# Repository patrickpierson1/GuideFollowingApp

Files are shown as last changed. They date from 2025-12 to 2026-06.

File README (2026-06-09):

AIChair: Guide Following Documentation
By Joseph Loreen, Marlen Vining and Patrick Pierson

1.0 Project Overview
AIChair Guide Following is a wheelchair person following system designed to help wheelchair users navigate by following a person. The system is designed to provide an accessible and user-friendly interface to a YOLO backend for the autonomous tracking and following of a human guide. It enables a user to select a person for the system to follow. 

The system will then drive the chair to maintain a set distance from the guide. The system consists of an IOS app as a frontend and a Raspberry Pi as a backend. The app includes a view from the camera, a toggle for the backend tracking, the ability to select one of the tracked people to follow, and a settings menu. The backend uses a YOLO object detection model to draw boxes around any people in the images provided by the frontend. It uses the position of these boxes to drive the chair through the injection of RNET messages to face and follow the guide.

This documentation covers the setup of both the frontend application and the backend. It also provides an explanation of the key functions in each part of the system. This documentation ends with an overview of how the system functions and some limitations we have encountered. 

2.0 Backend Application
2.1 Overview
The backend application is designed to run on a Raspberry Pi 5 and serves as the main processing and control layer for the guide-following wheelchair system. It communicates wirelessly with the frontend application, which streams image frames from the phone camera to the backend in real time. The backend processes each incoming image, performs person detection, tracks detected individuals across frames, and generates control commands that are sent to the wheelchair through the RNET communication system.
Human detection is performed using YOLO, which identifies people within each received camera frame and returns bounding box information for each valid detection. Detections below the configured confidence threshold are discarded to reduce false positives and improve tracking reliability. Once detections are generated, the tracking system assigns and maintains consistent IDs for each detected person. This allows the backend to distinguish between multiple people in the frame and continue identifying the same individual as they move.
Person tracking is handled using an intersection-over-union based tracking approach. For each new frame, the tracker compares the bounding boxes from the current YOLO detections against the bounding boxes from the previous frame. If two bounding boxes overlap enough, they are treated as the same person and the previous ID is preserved. This allows detections to be mapped to stable person IDs over time.
The backend supports different operating states. In tracking mode, the system detects and tracks all visible people, allowing the frontend to select a specific person ID. Once a target person is selected, the backend transitions into following mode. In following mode, the backend monitors the selected person’s bounding box, calculates the normalized center position of that person in the frame, and determines the direction the wheelchair should move in order to follow them. These direction commands are written to a shared thread-safe control interface.
The control system reads these shared joystick values and converts them into RNET-compatible CAN messages. These messages emulate joystick commands and are injected onto the wheelchair CAN bus, allowing the backend to command movement through the chair’s existing motor controller interface. This separates the image-processing pipeline from the low-level chair-control pipeline while still allowing both systems to communicate safely through shared mutex-protected variables.
2.2 System Requirements
Hardware Requirements
The backend is intended to run on the following hardware:
Raspberry Pi 5
Raspberry Pi AI HAT rated for 14 TOPS
PiCAN HAT with DC/DC power support
RNET-compatible powered wheelchair system
CAN connection from the PiCAN HAT to the wheelchair RNET bus
The PiCAN HAT is used to interface with the wheelchair’s CAN network. The AI HAT is used to improve the performance of the image-processing pipeline, particularly YOLO-based human detection. The Raspberry Pi 5 acts as the central embedded computer that receives image data, runs backend logic, and sends control commands to the chair.
Software Requirements
The Raspberry Pi should be configured with a functional 64-bit Raspberry Pi OS image. Python must be installed, and a fresh virtual environment is recommended to isolate the backend dependencies from the system Python installation.
The backend requires Python packages for computer vision, machine learning inference, CAN communication, API hosting, and image handling. These packages are installed automatically using the provided setup.sh script.
2.3 Setup Instructions
Clone the Repository
Clone the project repository locally on the Raspberry Pi:
git clone https://github.com/patrickpierson1/GuideFollowingApp.git
Move into the backend directory:
cd GuideFollowingApp/backend
Connect the PiCAN HAT to the Wheelchair
Ensure that the PiCAN HAT is properly installed on the Raspberry Pi and connected to the wheelchair CAN bus. The chair-side wiring should be connected as follows:
12V  : Red wire
GND  : Black wire
CAN High : White wire
CAN Low  : Blue wire
Before powering the system, confirm that the wiring is secure and that CAN High and CAN Low are not reversed.
Run the Setup Script
The backend includes a setup.sh script to automate software setup. Instead of installing each package manually, run the setup script from inside the backend directory:
./setup.sh
If the script does not have execute permission, enable it first:
chmod +x setup.sh
./setup.sh
The setup script installs the required backend dependencies and prepares the Python environment. This includes packages for CAN communication, numerical processing, machine learning inference, API hosting, image processing, and YOLO object detection.
The setup script installs and configures dependencies such as:
python-can      CAN communication support from Python
can-utils       Linux CAN utilities for configuring and testing CAN interfaces
numpy           Numerical processing for detection and tracking data
torch           PyTorch machine learning framework
torchvision     Computer vision support for PyTorch
torchaudio      Audio package bundled with the PyTorch install set
fastapi         Backend API framework used to communicate with the frontend
uvicorn         ASGI server used to run the backend application
ultralytics     YOLO model support
pillow          Image loading and processing
python-multipart Support for receiving image uploads from the frontend
The script should be run before starting the backend for the first time. A fresh Python virtual environment is still recommended so that all packages remain isolated from the system Python installation.
Enable CAN Support
The Raspberry Pi must be configured to recognize the PiCAN HAT and enable the CAN interface. Add the following lines to the bottom of: /boot/firmware/config.txt
dtparam=spi=on
dtoverlay=mcp2515-can0,oscillator=16000000,interrupt=25
dtoverlay=spi-bcm2835-overlay
These configuration lines enable SPI communication and load the MCP2515 CAN controller overlay used by the PiCAN HAT.
After editing the configuration file, reboot the Raspberry Pi:
sudo reboot
Open the CAN Port and Set the Bit Rate
Once the Raspberry Pi has rebooted, initialize the CAN interface with a bit rate of 125000:
sudo /sbin/ip link set can0 up type can bitrate 125000
This opens the can0 interface and configures it to communicate at the correct RNET CAN bus speed.
To verify that the CAN interface is active, run:
ip link show can0
The interface should appear as active before running the backend.
Run the Backend
Start the backend server using Uvicorn:
uvicorn backend:app --reload --host 0.0.0.0 --port 8000 --no-access-log
Running with --host 0.0.0.0 allows the frontend device to connect to the Raspberry Pi over the local wireless network. The backend listens on port 8000.
After the backend starts, copy the Raspberry Pi’s IP address into the frontend application so the phone can send image frames to the backend.
2.4 File Structure
/backend/backend.py
backend.py is the main entry point for the backend application. It initializes the image-processing and control systems required for operation. On startup, it loads the YOLO models, initializes the person tracker, and starts a separate process for RNET communication with the wheelchair.
When the frontend sends an image frame to the backend, the frontend calls the backend detection endpoint. This causes backend.py to pass the image to the detection pipeline, where YOLO is used to identify people in the frame. The resulting detections are then passed to the tracking module, which updates person IDs and returns tracked detection data.
The backend then checks the current operating state. In tracking mode, it returns the detected people and their IDs so the frontend can display and select a target. In following mode, it uses the selected target ID to determine the person’s position in the frame and updates the shared joystick command values in Shared.py. These shared values are later read by the RNET injection system and converted into motor commands.
When the backend shuts down, active threads and processes are cleaned up automatically to prevent communication or control threads from continuing after the application has stopped.
Image Processing
/backend/ImageProcessing/detect.py
This module is responsible for running YOLO-based human detection. It receives image data from the backend, performs inference using the loaded YOLO model, and returns bounding box results for detected people.
The module filters detections based on a minimum confidence threshold. Any detection below this threshold is ignored. This reduces the chance of false detections being passed into the tracker and improves the reliability of the follow behavior.
The output of this module includes normalized detection data that can be used by the tracking system and frontend display logic.
/backend/ImageProcessing/track.py
This module manages person tracking across consecutive frames. Since YOLO detects people independently in each image, the raw detection results do not automatically preserve identity between frames. The tracking module solves this by assigning each detected person a persistent ID.
The tracker compares bounding boxes from the current frame to bounding boxes from the previous frame using intersection over union. If a current detection overlaps sufficiently with a previous detection, it is treated as the same person and keeps the same ID. If no suitable match is found, a new ID is assigned.
This allows the system to maintain consistent person identities even as people move through the camera frame. The module returns normalized detections with their associated person IDs.
/backend/ImageProcessing/guide.py
This module calculates the position of the selected tracked person relative to the camera frame. It uses the bounding box of the selected target and computes the center point of that box.
The returned center position is normalized so it can be interpreted as a directional guide value rather than a raw pixel coordinate. This normalized target location is used by the following logic to determine whether the wheelchair should move left, right, forward, or remain centered behind the selected person.
The guide module acts as the connection between visual tracking and motion control. It converts tracked image-space position into a simplified control reference that can be used by the chair-control system.
Controls
/backend/Controls/can2RNET.py
This module provides RNET communication support over CAN. It is a publicly available module used to help send, receive, inject, and dissect CAN frames on the wheelchair’s RNET communication bus.
Within this backend, can2RNET.py supports the lower-level CAN frame operations needed by the injection system. It allows the backend to construct and transmit messages that emulate joystick behavior on the RNET bus.
/backend/Controls/Connect.py
This module initializes the CAN connection to the wheelchair. It opens the CAN socket, prepares the system for RNET communication, and starts the required communication threads.
When enabled, this module can also start a keyboard input thread for manual joystick control. This is useful for testing CAN communication and motor response without running the image-detection pipeline.
During operation, Connect.py prints joystick commands being sent to the motor. This provides feedback for debugging and makes it easier to verify that the shared joystick values are being converted into outgoing control commands.
When the backend or control process is closed, this module handles thread cleanup so that injection and input-listening threads terminate properly.
/backend/Controls/Inject.py
This module is responsible for constructing and injecting joystick-emulation CAN frames. It first determines the correct joystick CAN ID used by the chair’s RNET system. Once the joystick ID is known, it builds CAN frames that represent joystick movement commands.
The joystick values are read from Shared.py. These values represent the desired x and y joystick position, which may come from the image-following system or from manual keyboard control. Inject.py converts these shared values into RNET-compatible CAN messages and injects them onto the CAN bus.
This module is the final step between the backend’s control decision and the wheelchair motor controller. It translates high-level movement commands into low-level CAN traffic.
/backend/Controls/KeyboardCtrl.py
This optional module listens for keyboard input from the terminal and updates joystick commands based on arrow-key input. It is mainly intended for testing and debugging the RNET control path without using the camera or YOLO detection pipeline.
When an arrow key is pressed, the module updates the shared joystick x and y values in Shared.py. These values are then read by the injection system and sent to the wheelchair as joystick commands.
Note: KeyboardCtrl.py should not be run at the same time as image detection or following mode. Both systems update the same shared joystick command values, so running them together may cause conflicting control commands.
/backend/Controls/Shared.py
This module provides a shared mutex-protected interface for joystick control values. It stores the joystick x and y variables and provides functions for safely updating or resetting them from multiple threads.
Because the backend uses separate processes and threads for detection, tracking, keyboard input, and CAN injection, shared state must be protected to prevent inconsistent or conflicting values. Shared.py acts as the common communication point between these systems.
The image-following pipeline writes updated movement commands to Shared.py, while the CAN injection system reads from it when building joystick frames. This allows the system to separate perception logic from low-level chair control while still maintaining safe communication between threads.

3.0 Swift App Documentation
3.1 Overview
The AIChair Guide Following app captures live video from the iPhones camera and sends the frames to the Python backend for processing. The backend performs person detection and tracking then returns bounding box coordinates which the app then displays on screen. Users can tap these boxes to select which person the wheelchair should lock onto and follow.

The app also uses the iPhones LiDAR camera to estimate the distance of detected individuals. For each detected person the app samples multiple points inside the bounding box and uses the minimum depth value to estimate the distance. This distance is then displayed on the bounding box associated with the detected person and is used to help maintain a safe following distance from the guide.

The app is written in Swift using SwiftUI. When tracking is enabled frames from the camera are sent to the backend using HTTP POST requests. Currently the app communicates with the backend through a hotspot hosted by the Raspberry pi which allows the app and backend to communicate without relying on an external network.

3.2 System Requirements
Hardware:
iPhone that supports iOS 15 or later and includes a LiDAR sensor for depth estimation (We are testing on an iPhone 13 Pro)
Raspberry Pi running the backend and hosting a hotspot connection
Development:
macOS with Xcode
Apple ID for deploying the app through Xcode

3.3 Setup Instructions
First Time Setup instructions on Xcode
Clone the repository from GitHub
Open the project in Xcode
Plug your iPhone into your Mac using a USB cable. You'll be asked on your phone if you trust this computer and select trust.
In Xcode select Window -> Devices and Simulators and make sure your iPhone appears under Connected devices.
In the left sidebar of Xcode click the project name in this case GuideFollowing. Then go to Signing & Capabilities.
Under team select your Apple ID. If it's not listed add your Apple account. Make sure Automatically manage signing is enabled.
Select your iPhone as the run destination at the top of Xcode
Click the run button or press Cmd + R to build and install the app onto your phone.
Since it's your first time running the app your iPhone will display Untrusted Developer. On your phone go to Settings -> General -> VPN & Device Management - > Developer app -> Trust
Launch the app and make sure to allow Camera Access.
After First Setup: The app will be installed on your phone and can be launched directly from it. If you make any code changes, rebuild and run from Xcode. Once your phone has been paired with your mac you can build wirelessly. Just make sure that both your mac and iPhone are on the same WiFi.

3.4 File Structure
/swift-app/GuideFollowing/CameraView.swift
Main interface for the app
Displays the live camera feed and overlays bounding boxes using the detection results from the backend
Handles user interaction for selecting a guide, starting and stopping tracking, pressing the move and stop button, and opening the settings menu
boxRect() converts the backend coordinates into on screen box positions and dimensions.
Displays status when someone is selected like “Following ID: _” or “Lost Track of ID: _”
Displays the ID and distance estimate associated with each detected person
/swift-app/GuideFollowing/CameraManager.swift
Handles all camera functionality
Sets up the camera session and captures frames using AVCaptureSession
Calls captureOutput() when a frame is ready
Passes frames through the onFrameCaptured closure
Captures depth data from the iPhone’s LiDAR camera and passes it through the onDepthCaptured closure
/swift-app/GuideFollowing/NetworkManager.swift
Handles communication between the app and the backend server
Converts frames into JPEG images and sends them to the /detect endpoint using HTTP POST
buildRequest() builds the HTTP POST request with the JPEG Image, selected guide ID, movement status, stopping distance, and maximum speed
Decodes the returned JSON data into DetectedPerson objects and updates the UI
Calculates distance estimates using the iPhone depth map by sampling 5 points inside each detected person’s bounding box and taking the minimum depth value
There are also functions for starting and stopping tracking, and resetting the ID tracker
/swift-app/GuideFollowing/SettingsView.swift
Allows the user to edit the backend IP address
Displays backend connection status
Allows the user to adjust stopping distance using a slider
Allows the user to adjust maximum following speed using a slider
Includes a Reset Tracker button to clear all tracked IDs and restart tracking
/swift-app/GuideFollowing/GuideFollowingApp.swift
Entry point for the app
Launches CameraView as the main screen

3.5 How it works
When the app is launched CameraManager initializes the iPhone camera and begins capturing video frames and depth data from the LiDAR camera. These frames are displayed in CameraView which shows the live feed to the user. When tracking is enabled each captured frame is sent to the backend server through NetworkManager along with information such as the selected guide ID, movement status, stopping distance, and maximum speed. The backend performs person detection and tracking using the YOLO model and returns a list of detected people along with their bounding box coordinates and tracking IDs.

NetworkManager converts this response into DetectedPerson objects and calculates a distance estimate for each detected person using the iPhones depth map. This is done by sampling five points inside each detected person’s bounding box and using the minimum depth value as the estimated distance. The calculated distance is then assigned to the detected person.

Once the detected people array is updated SwiftUI automatically redraws the interface and updates the bounding boxes, IDs, and distance values displayed on screen.

Users can then tap on the bounding box to select which person the wheelchair should follow. The selected ID is highlighted in the interface and is included in the future requests sent to the backend so the same guide can continue to be tracked across frames. Once a guide has been selected the user can press the Move button to begin following them while maintaining the chosen stopping distance.

3.6 Limitations
Tracking ID problems: The tracking IDs assigned to people can change if a person leaves the camera frame for a few seconds or if people overlap.
Low frame rate, roughly ~2 fps makes following a guide around harsh corners difficult

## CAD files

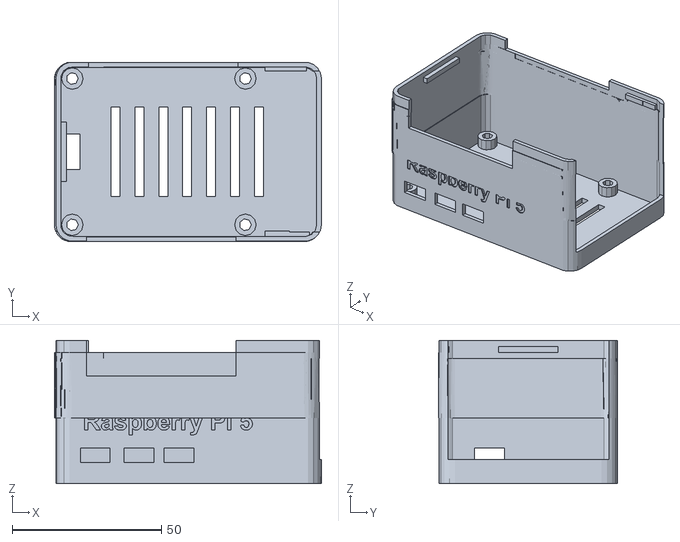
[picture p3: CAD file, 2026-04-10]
case-models/case.stl
89.5 x 60.1 x 48.0

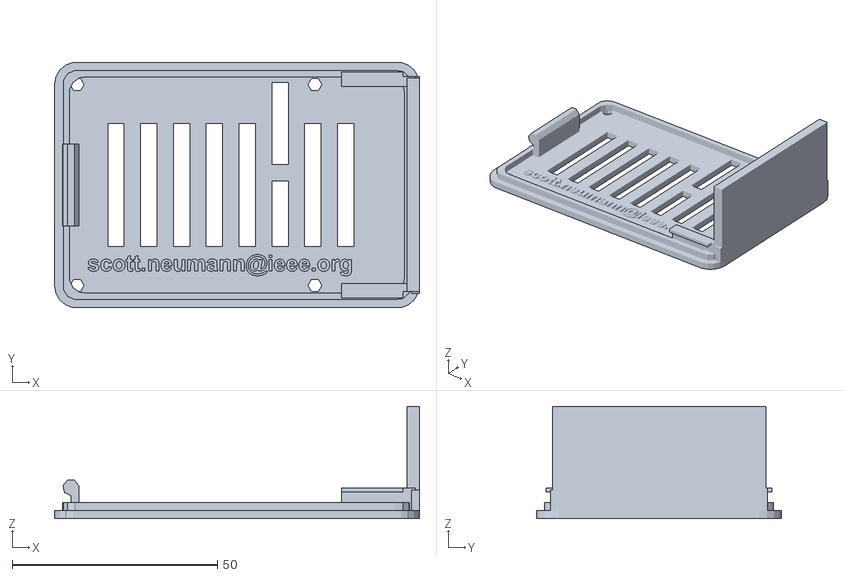
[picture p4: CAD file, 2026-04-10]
case-models/lid.stl
89.0 x 59.8 x 27.4

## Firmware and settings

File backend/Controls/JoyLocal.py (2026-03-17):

#!/python3
# joystick based on: https://www.kernel.org/doc/Documentation/input/joystick-api.txt

#Requires: socketCan, can0 interface

# This file is part of can2RNET.
#
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
import socket, sys, os, array, threading
from time import *
from fcntl import ioctl
from can2RNET import *


debug = True


#JoyLocal.py - Translate USB joystick x/y axis to Rnet and inject onto canbus
class X360:

    axis_map = []
    button_map = []
    xthreshold = 8 * 0x10000 / 128
    ythreshold = 8 * 0x10000 / 128

    joystick_x = 0
    joystick_y = 0


    # We'll store the states here.
    axis_states = {}
    button_states = {}

    # These constants were borrowed from linux/input.h
    axis_names = {
        0x00 : 'x',
        0x01 : 'y',
        0x02 : 'z',
        0x03 : 'rx',
        0x04 : 'ry',
        0x05 : 'rz',
        0x06 : 'trottle',
        0x07 : 'rudder',
        0x08 : 'wheel',
        0x09 : 'gas',
        0x0a : 'brake',
        0x10 : 'hat0x',
        0x11 : 'hat0y',
        0x12 : 'hat1x',
        0x13 : 'hat1y',
        0x14 : 'hat2x',
        0x15 : 'hat2y',
        0x16 : 'hat3x',
        0x17 : 'hat3y',
        0x18 : 'pressure',
        0x19 : 'distance',
        0x1a : 'tilt_x',
        0x1b : 'tilt_y',
        0x1c : 'tool_width',
        0x20 : 'volume',
        0x28 : 'misc',
    }

    button_names = {
        0x120 : 'trigger',
        0x121 : 'thumb',
        0x122 : 'thumb2',
        0x123 : 'top',
        0x124 : 'top2',
        0x125 : 'pinkie',
        0x126 : 'base',
        0x127 : 'base2',
        0x128 : 'base3',
        0x129 : 'base4',
        0x12a : 'base5',
        0x12b : 'base6',
        0x12f : 'dead',
        0x130 : 'a',
        0x131 : 'b',
        0x132 : 'c',
        0x133 : 'x',
        0x134 : 'y',
        0x135 : 'z',
        0x136 : 'tl',
        0x137 : 'tr',
        0x138 : 'tl2',
        0x139 : 'tr2',
        0x13a : 'select',
        0x13b : 'start',
        0x13c : 'mode',
        0x13d : 'thumbl',
        0x13e : 'thumbr',

        0x220 : 'dpad_up',
        0x221 : 'dpad_down',
        0x222 : 'dpad_left',
        0x223 : 'dpad_right',

        # XBox 360 controller uses these codes.
        0x2c0 : 'dpad_left',
        0x2c1 : 'dpad_right',
        0x2c2 : 'dpad_up',
        0x2c3 : 'dpad_down',
    }

    def init_joystick(self):

        if debug:
            # Iterate over the joystick devices.
            print('Available devices:')

            for fn in os.listdir('/dev/input'):
                if fn.startswith('js'):
                    print('  /dev/input/%s' % (fn))

        # Open the joystick device.
        try:
            fn = '/dev/input/js0'
            if debug:
                print('Opening %s...' % fn)
            jsdev = open(fn, 'rb')
        except IOError:
            print ('No joystick at ' + fn)
            return ('')


        #jsdev = os.open(fn, 'rb', os.O_RDONLY|os.O_NONBLOCK)

        # Get the device name.
        #buf = bytearray(63)
        buf = bytearray([0] * 64)
        ioctl(jsdev, 0x80006a13 + (0x10000 * len(buf)), buf) # JSIOCGNAME(len)
        js_name = buf

        if debug:
            print('Device name: %s' % js_name)

        # Get number of axes and buttons.
        buf = array.array('B', [0] )
        ioctl(jsdev, 0x80016a11, buf) # JSIOCGAXES
        num_axes = buf[0]

        buf = array.array('B', [0] )
        ioctl(jsdev, 0x80016a12, buf) # JSIOCGBUTTONS
        num_buttons = buf[0]

        # Get the axis map.
        buf = array.array('B', [0] * 0x40)
        ioctl(jsdev, 0x80406a32, buf) # JSIOCGAXMAP

        for axis in buf[:num_axes]:
            axis_name = self.axis_names.get(axis, 'unknown(0x%02x)' % axis)
            self.axis_map.append(axis_name)
            self.axis_states[axis_name] = 0.0

        # Get the button map.
        buf = array.array('H', [0] * 200)
        ioctl(jsdev, 0x80406a34, buf) # JSIOCGBTNMAP

        for btn in buf[:num_buttons]:
            btn_name = self.button_names.get(btn, 'unknown(0x%03x)' % btn)
            self.button_map.append(btn_name)
            self.button_states[btn_name] = 0

        if debug:
            print ('%d axes found: %s' % (num_axes, ', '.join(self.axis_map)))
            print ('%d buttons found: %s' % (num_buttons, ', '.join(self.button_map)))
        return (jsdev)

    def usb_joystick_read_thread(self, jsdev):
        global joystick_x
        global joystick_y
        global rnet_threads_running

        while rnet_threads_running:
            try:
                evbuf = jsdev.read(8)
                jtime, jvalue, jtype, jnumber = struct.unpack('IhBB', evbuf)

                if jtype & 0x02:
                    axis = self.axis_map[jnumber]
                    if (axis == 'x'):
                            if abs(jvalue) > self.xthreshold:
                                    joystick_x = 0x100 + int(jvalue * 100 / 128) >> 8 &0xFF
                            else:
                                    joystick_x = 0
                    elif (axis == 'y'):
                            if abs(jvalue) > self.ythreshold:
                                    joystick_y = 0x100 - int(jvalue * 100 / 128) >> 8 &0xFF
                            else:
                                    joystick_y = 0

            except:
                print("Error reading USB: joystick")
                joystick_x = 0
                joystick_y = 0
                rnet_threads_running = False

def dec2hex(dec,hexlen):  #convert dec to hex with leading 0s and no '0x'
    h=hex(int(dec))[2:]
    l=len(h)
    if h[l-1]=="L":
        l-=1  #strip the 'L' that python int sticks on
    if h[l-2]=="x":
        h= '0'+hex(int(dec))[1:]
    return ('0'*hexlen+h)[l:l+hexlen]

def induce_JSM_error(cansocket):
    for i in range(0,3):
        cansend(cansocket,'0c000000#')

def RNET_JSMerror_exploit(cansocket):
    print("Waiting for JSM heartbeat")
    canwait(cansocket,"03C30F0F:1FFFFFFF")
    t=time()+0.20

    print("Waiting for joy frame")
    joy_id = wait_rnet_joystick_frame(cansocket,t)
    print("Using joy frame: "+joy_id)

    induce_JSM_error(cansocket)
    print("3 x 0c000000# sent")

    return(joy_id)

#THREAD: sends RnetJoyFrame every mintime seconds
def send_joystick_canframe(s,joy_id):
    mintime = .01
    nexttime = time() + mintime
    priorjoystick_x=joystick_x
    priorjoystick_y=joystick_y
    while rnet_threads_running:
        joyframe = joy_id+'#'+dec2hex(joystick_x,2)+dec2hex(joystick_y,2)
        cansend(s,joyframe)
        nexttime += mintime
        t= time()
        if t < nexttime:
            sleep(nexttime - t)
        else:
            nexttime += mintime

#THREAD: Waits for joyframe and injects another spoofed frame ASAP
def inject_rnet_joystick_frame(can_socket, rnet_joystick_id):
	rnet_joystick_frame_raw = build_frame(rnet_joystick_id + "#0000") #prebuild the frame we are waiting on
	while rnet_threads_running:
		cf, addr = can_socket.recvfrom(16)
		if cf == rnet_joystick_frame_raw:
			cansend(can_socket, rnet_joystick_id + '#' + dec2hex(joystick_x, 2) + dec2hex(joystick_y, 2))


#Waits for any frame containing a Joystick position
#Returns: JoyFrame extendedID as text
def wait_rnet_joystick_frame(can_socket, start_time):
    frameid = ''

    while frameid[0:3] != '020':  #just look for joystick frame ID (no extended frame)
        cf, addr = can_socket.recvfrom(16) #this is a blocking read.... so if there is no canbus traffic it will sit forever (to fix!)
        candump_frame = dissect_frame(cf)
        frameid = candump_frame.split('#')[0]
        if time() > start_time:
             print("JoyFrame wait timed out ")
             return('Err!')
    return(frameid)

#Set speed_range: 0% - 100%
def RNETsetSpeedRange(cansocket,speed_range):
    if speed_range>=0 and speed_range<=0x64:
        cansend(cansocket,'0a040100#'+dec2hex(speed_range,2))
    else:
        print('Invalid RNET SpeedRange: ' + str(speed_range))

def RNETshortBeep(cansocket):
    cansend(cansocket,"181c0100#0260000000000000")

#Play little song
def RNETplaysong(cansocket):
    cansend(cansocket,"181C0100#2056080010560858")
    sleep(.77)
    cansend(cansocket,"181C0100#105a205b00000000")

#do very little and output something as sign-of-life
def watch_and_wait():
    started_time = time()
    while threading.active_count() > 0 and rnet_threads_running:
        sleep(0.5)
        print(str(round(time()-started_time,2))+'\tX: '+dec2hex(joystick_x,2)+'\tY: '+dec2hex(joystick_y,2)+ '\tThreads: '+str(threading.active_count()))

#does not use a thread queue.  Instead just sets a global flag.
def kill_rnet_threads():
    global rnet_threads_running
    rnet_threads_running = False

# Makes sure that gamepad is centered.
def check_usb_gamepad_center():
    print('waiting for joystick to be centered')
    while (joystick_x !=0 or joystick_y !=0):
        print('joystick not centered')

def selectControlExploit(can_socket):
    user_selection = int(input("Select exploit to use: \n \n 1. Disable R-Net Joystick temporary. (Allows for better control) \n 2. Allow R-Net Joystick (Will see some lag, but is more safe.)\n"))


    if (user_selection == 1):
        print("\n You chose to disable the R-Net Joystick temporary. Restart the chair to fix. ")
        start_time = time() + .20
        print('Waiting for RNET-Joystick frame')

        rnet_joystick_id = wait_rnet_joystick_frame(can_socket, start_time) #t=timeout time
        if rnet_joystick_id == 'Err!':
            print('No RNET-Joystick frame seen within minimum time')
            sys.exit()
        print('Found RNET-Joystick frame: ' + rnet_joystick_id)

        # set chair's speed to the lowest setting.
        chair_speed_range = 00
        RNETsetSpeedRange(can_socket, chair_speed_range)

        rnet_joystick_id = RNET_JSMerror_exploit(can_socket)

        sendjoyframethread = threading.Thread(
            target=send_joystick_canframe,
            args=(can_socket,rnet_joystick_id,),
            daemon=True)
        sendjoyframethread.start()
    elif (user_selection == 2):
        print("\n You chose to allow the R-Net Joystick.")
        start_time = time() + .20
        print('Waiting for RNET-Joystick frame')

        rnet_joystick_id = wait_rnet_joystick_frame(can_socket, start_time) #t=timeout time
        if rnet_joystick_id == 'Err!':
            print('No RNET-Joystick frame seen within minimum time')
            sys.exit()
        print('Found RNET-Joystick frame: ' + rnet_joystick_id)


        # set chair's speed to the lowest setting.
        chair_speed_range = 00
        RNETsetSpeedRange(can_socket, chair_speed_range)


        inject_rnet_joystick_frame_thread = threading.Thread(
            target=inject_rnet_joystick_frame,
            args=(can_socket, rnet_joystick_id,),
            daemon=True)
        inject_rnet_joystick_frame_thread.start()



if __name__ == "__main__":
    global rnet_threads_running
    global joystick_x
    global joystick_y
    rnet_threads_running = True
    can_socket = opencansocket(0)

    #init usb joystick
    x360 = X360()
    usb_joystick_dev = x360.init_joystick()
    joystick_x = 0
    joystick_y = 0

    if usb_joystick_dev != '':
        print('Using USB joystick @ ' + str(usb_joystick_dev).split("'")[1])
        usb_joystick_read_thread = threading.Thread(
            target=x360.usb_joystick_read_thread,
            args=(usb_joystick_dev,),
            daemon=True)
        usb_joystick_read_thread.start()

        check_usb_gamepad_center()
        selectControlExploit(can_socket)

        sleep(0.5)
        watch_and_wait()
        kill_rnet_threads()
    else:
        print('No Joystick found.')
        kill_rnet_threads()


    print("Exiting")

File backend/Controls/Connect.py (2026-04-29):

# /backend/Controls/Connect.py
import sys
import socket
import threading
from time import sleep, time
try:
    from .can2RNET import cansend, opencansocket
    from .Inject import inject, getJoystickID
    from .KeyboardCtrl import keyboard_control
    from . import Shared
except ImportError:
    from can2RNET import cansend, opencansocket
    from Inject import inject, getJoystickID
    from KeyboardCtrl import keyboard_control
    import Shared

# converts dec to hex (zero-padded)
def dec2hex(dec, hexlen):
    h = hex(int(dec))[2:]
    return ('0' * hexlen + h)[-hexlen:]

# injects the speed range into the RNET system, 0-255
def RNETsetSpeedRange(can_socket, speed_range):
    # speed_range expected 0..255
    frame = '0A040100#' + dec2hex(speed_range, 2) + '00'
    print("RNETsetSpeedRange sending:", frame)
    cansend(can_socket, '0A040100#' + dec2hex(speed_range, 2))

# connects to RNET bus
def connect(use_keyboard=False):

    # Open CAN socket
    can_socket = opencansocket(0)
    if can_socket == '':
        print('Cannot open CAN interface, exiting.')
        sys.exit()
    can_socket.settimeout(0.1)
    print("CAN socket opened successfully.")

    # Wait for joystick frame to identify the correct ID
    print("Waiting for RNET-Joystick frame")
    joy_id = getJoystickID(can_socket, time() + 0.20)
    if joy_id == "Err!":
        can_socket.close()
        sys.exit()
    print("Found:", joy_id)

    # On startup, set speed to 0 (minimum) to ensure a known state
    RNETsetSpeedRange(can_socket, 0)

    # Start threads for keyboard control and CAN injection
    print(f"Keyboard control {'enabled' if use_keyboard else 'disabled'}")
    kb_thread = None
    inj_thread = threading.Thread(target=inject, args=(can_socket, joy_id))
    if use_keyboard:
        kb_thread = threading.Thread(target=keyboard_control)
        kb_thread.start()
    inj_thread.start()
    start = time()

    # Keep track of last applied speed byte to avoid redundant frames
    last_applied_speed_byte = None
    # Keep track of last seen timestamp of the max-speed file so we can detect changes
    last_maxspeed_ts = 0.0

    # Main loop to print joystick state every 0.5 seconds, and handle graceful shutdown on Ctrl+C
    try:
        while not Shared.stop_event.is_set():
            sleep(0.5)

            # Read file-backed max speed state and apply if changed (always apply first time)
            try:
                current_ts = Shared.get_max_speed_state_timestamp()
                if current_ts and current_ts != last_maxspeed_ts:
                    last_maxspeed_ts = current_ts
                    new_percent = Shared.get_max_speed_percent()
                    if new_percent is None:
                        speed_byte = 0
                    else:
                        speed_byte = int(new_percent)
                    if speed_byte != last_applied_speed_byte:
                        frame = '0A040100#' + dec2hex(speed_byte, 2) + '00'
                        print(f"Applying max speed -> {new_percent} % -> frame: {frame}")
                        RNETsetSpeedRange(can_socket, speed_byte)
                        last_applied_speed_byte = speed_byte
            except Exception as e:
                print("Error applying max speed:", e)

            joystick_x, joystick_y = Shared.get_joystick()
            print(
                f"{round(time()-start, 2)}s  "
                f"X:{dec2hex(joystick_x,2)}  "
                f"Y:{dec2hex(joystick_y,2)}"
            )

    # Handle Ctrl+C for graceful shutdown
    except KeyboardInterrupt:
        print("\nStopping...")
        Shared.stop_event.set()

    # Ensure all threads are stopped and resources are cleaned up
    finally:
        Shared.stop_event.set()
        Shared.reset_joystick()

        try:
            can_socket.close()
        except Exception:
            pass

        if kb_thread is not None:
            kb_thread.join(timeout=1.0)
        inj_thread.join(timeout=1.0)

        print("Exiting cleanly")

if __name__ == "__main__":
    use_keyboard = "--no-keyboard" not in sys.argv
    connect(use_keyboard=use_keyboard)

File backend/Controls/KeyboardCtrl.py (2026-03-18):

# /backend/Controls/KeyboardCtrl.py
import os
import sys
import termios
import tty
import select
from time import time
try:
    from . import Shared
except ImportError:
    import Shared

ARROW_HOLD_TIME = 0.18
KEYBOARD_COMMAND_HOLD_SECONDS = 0.25

# reads all available data from stdin without blocking
def read_available_stdin():
    data = ""
    fd = sys.stdin.fileno()

    while True:
        ready, _, _ = select.select([sys.stdin], [], [], 0)
        if not ready:
            break
        chunk = os.read(fd, 64)
        if not chunk:
            break
        data += chunk.decode(errors="ignore")
        if len(chunk) < 64:
            break
    return data

# parses the input buffer for arrow key sequences and updates the joystick state accordingly
def update_arrow_state_from_buffer(buf):
    i = 0

    # Arrow keys send escape sequences like '\x1b[A' for up, '\x1b[B' for down, etc.
    while i < len(buf):
        ch = buf[i]
        if ch.lower() == 'q':
            Shared.stop_event.set()
            i += 1
            continue
        if ch == '\x1b':
            if i + 2 >= len(buf):
                return buf[i:]
            if buf[i + 1] == '[':
                code = buf[i + 2]
                now = time()

                # Update the last press time for the corresponding arrow key
                if code == 'A':
                    Shared.last_up = now
                    i += 3
                    continue
                elif code == 'B':
                    Shared.last_down = now
                    i += 3
                    continue
                elif code == 'C':
                    Shared.last_right = now
                    i += 3
                    continue
                elif code == 'D':
                    Shared.last_left = now
                    i += 3
                    continue
            i += 1
            continue
        i += 1
    return ""

# main function to handle keyboard input and update joystick state based on arrow key presses
def keyboard_control():

    # Save original terminal settings and set to cbreak mode for non-blocking input
    fd = sys.stdin.fileno()
    old_settings = termios.tcgetattr(fd)
    pending = ""
    try:
        tty.setcbreak(fd)

        # Main loop to read keyboard input and update joystick state based on arrow key presses
        while not Shared.stop_event.is_set():
            ready, _, _ = select.select([sys.stdin], [], [], 0.01)

            # If there's input ready, read it and update the arrow key states
            if ready:
                pending += read_available_stdin()
                pending = update_arrow_state_from_buffer(pending)

            now = time()

            # Determine if each arrow key is currently active based on the last press time and the defined hold time
            up_active = (now - Shared.last_up) < ARROW_HOLD_TIME
            down_active = (now - Shared.last_down) < ARROW_HOLD_TIME
            left_active = (now - Shared.last_left) < ARROW_HOLD_TIME
            right_active = (now - Shared.last_right) < ARROW_HOLD_TIME

            x = 0x00
            y = 0x00

            # Set joystick X and Y values based on which arrow keys are active
            if left_active and not right_active:
                x = 0x9D
                y = 0x64
            elif right_active and not left_active:
                x = 0x64
                y = 0x64
            if up_active and not down_active:
                y = 0x64
            elif down_active and not up_active:
                y = 0x9D

            # Update the shared joystick state with the new X and Y values
            Shared.set_joystick(x, y, hold_seconds=KEYBOARD_COMMAND_HOLD_SECONDS)

    finally:
        termios.tcsetattr(fd, termios.TCSADRAIN, old_settings)

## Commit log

2025-12-20 implemented following, allows for the selection of a detected person and will continue following them using frame matching
2025-12-20 added settings page to allow for dev tools and options on phone. added flash control for rear camera use
2025-12-20 increased frame rate of main capture loop reducing latency
2026-01-23 Completed the basic camera functionality
2026-01-26 Updated the Start/Stop tracking button so it actually works
2026-03-11 Added a reset tracker button in settings. Also added a way to quickly switch between either a wireless or wired connection
2026-03-17 updated rnet drivers
2026-03-17 re organized backend and implemented can drivers
2026-03-17 Fixed zombie process issue on rnet drivers
    [Connect.py, Inject.py, JoyLocal.py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]
2026-03-17 updated backend to talk to rnet thread
2026-04-08 added Lidar need to test a lot to make sure its working
2026-04-10 add case model directory & 1st prototype
    [case.stl, lid.stl]

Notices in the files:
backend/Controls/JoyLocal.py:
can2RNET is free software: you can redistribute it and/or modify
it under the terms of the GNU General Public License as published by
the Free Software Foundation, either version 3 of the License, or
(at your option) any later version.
